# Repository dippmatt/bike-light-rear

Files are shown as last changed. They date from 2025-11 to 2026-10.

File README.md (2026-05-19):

# bike-light-rear

High-visibility rear bicycle light with Bluetooth Low Energy (BLE) control, featuring smart motion detection, ambient light sensing, and efficient single-cell Li-ion power management. Designed for hybrid assembly (pick-and-place for 0402/0603 passives, hand-soldering for connectors and high-value components).

## Hardware architecture

### Compute & wireless
- **BL653 module** (453-00039R) – Nordic nRF52833 SoC with integrated PCB trace antenna, Bluetooth 5.1, and 64 MHz Arm Cortex-M4F
- **Programming** – 2×3 1.27mm SWD header for firmware flashing and debugging
- **System power** – 2.7V from NPM1100 buck regulator optimized for 90-95% battery capacity utilization (3.11V cutoff)

### Sensors (I2C bus @ 2.7V)
- **LIS3DH accelerometer** – 3-axis motion detection (braking / fall detection) for brake/acceleration events, configurable thresholds, interrupt-driven
- **OPT3001 light sensor** – 0.01-83k lux range with human-eye spectral matching for automatic brightness control and day/night mode switching

### High-power LED driver
- **Cree XP-E2** (XPEBRD-L1-0000-00801) – 625nm Red emitter driven at 500mA via PAM2804 step-down constant-current driver
- **Control** – PWM dimming via BL653 GPIO with 100kΩ pull-down for safe default-off state

### Power subsystem
- **Battery** – Single 18350 Li-ion cell (Vapcell 1100mAh, unprotected), 3.11-4.2V operating range
- **Charging** – USB-C PD sink (5.1kΩ CC resistors), NPM1100 linear charger @ 400mA (0Ω ICHG resistor), 4.2V termination
- **Protection** – DW01A IC with dual AO3400A N-channel MOSFETs (drain-to-drain configuration) for over-voltage (4.3V), under-voltage (2.5V), and over-current (>2A) protection
- **Buck regulator** – NPM1100 internal 2.7V @ 150mA output
- **Status monitoring** – CHG and ERR signals routed to BL653 GPIO for firmware-based charge status indication
- **NTC disable** – Thermal monitoring disabled via 10kΩ resistor from NTC pin to AVSS (GND)

### PCB specifications
- **Design tool** – KiCad 9.0 (schema version `20250114`)
- **Test points** – Critical nets labeled for bring-up and debugging (+BATT, +VSYS, +VDD_nRF, GND, I2C_SDA, I2C_SCL)

### Hardware photos

Assembled PCB on the 18350 battery holder (angled view).

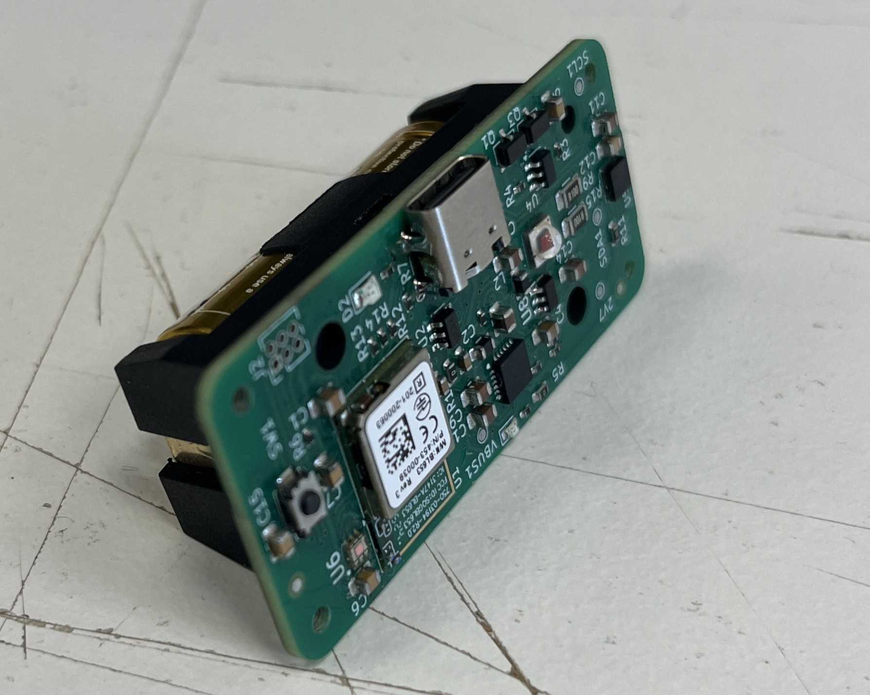
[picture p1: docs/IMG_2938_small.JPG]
Assembled PCB on battery pack


Top of the populated PCB: BL653 (nRF52833), USB-C, tactile switch, RGB status LED, SWD header (J2), and I2C test point pads for the accelerometer and ambient light sensor.

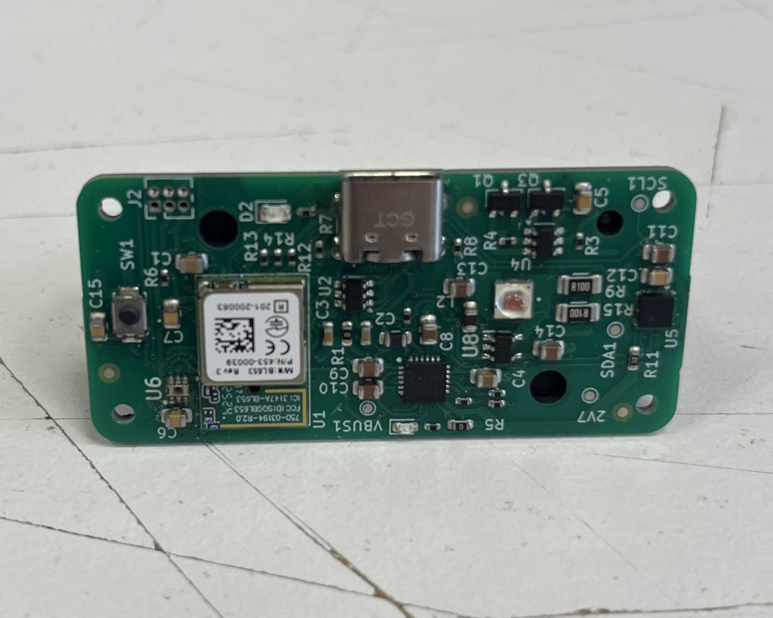
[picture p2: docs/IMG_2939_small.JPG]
PCB top view


Front of the 3D-printed enclosure with the Cree red main LED and status indicator.

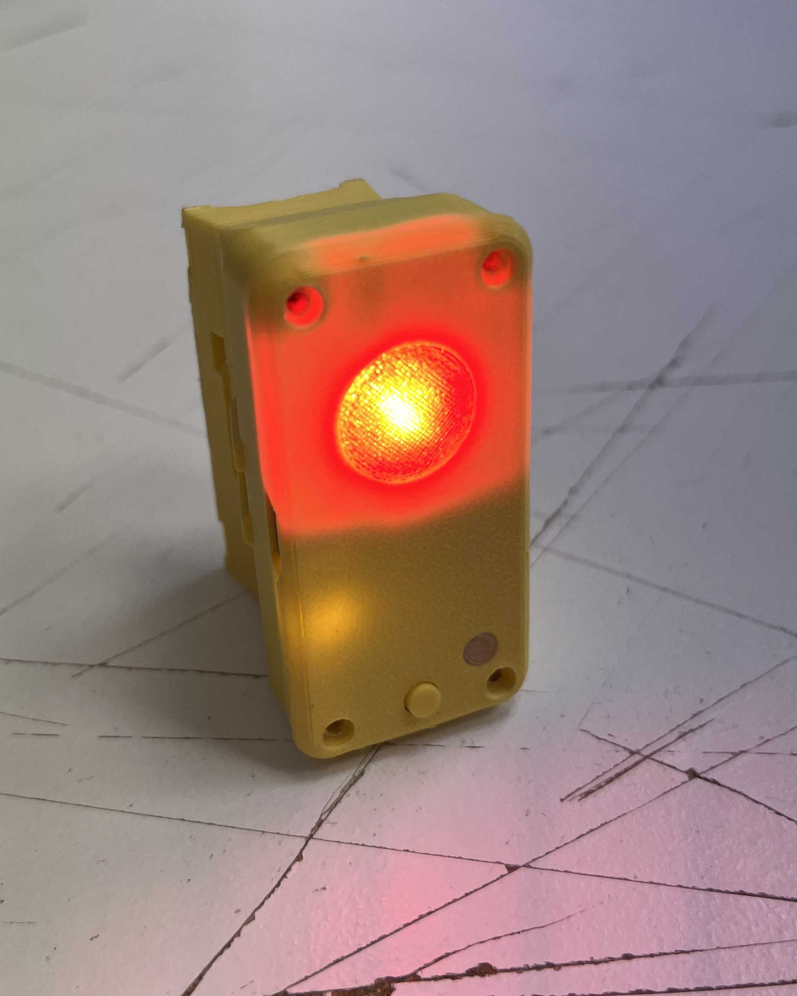
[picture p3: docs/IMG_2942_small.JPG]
Enclosure front, LEDs on


Side of the enclosure showing the USB charge port.

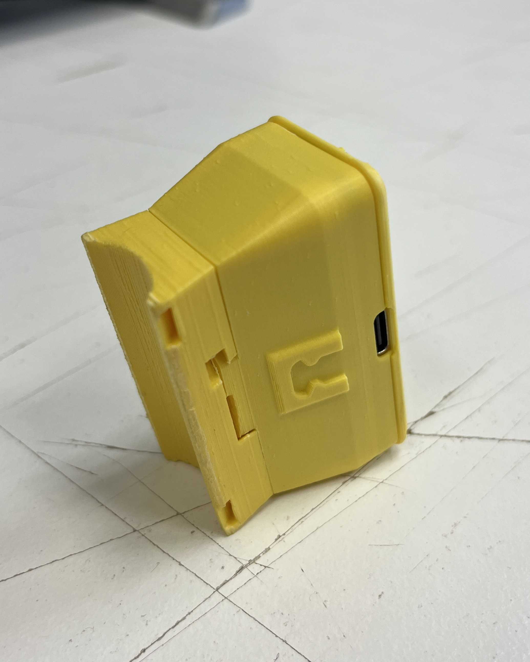
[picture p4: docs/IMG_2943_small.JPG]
Enclosure side, charge port and mount


## Repository layout
- `hardware/` – KiCad project, fabrication-toolkit config, custom libs (`kicad_symbols/`, `kicad_footprints/`, `kicad_3d_models/`), datasheets (markdown format), and generated BOM
- `software/rear_light_peripheral/` – main rear light firmware (Zephyr/nRF Connect SDK), including Smart Mode, BLE peripheral control, charging/idle state, and low-power sleep
- `software/front_light_central/` – proof-of-concept central/front-light firmware (experimental; will evolve later)
- `software/` *(other folders)* – development history and experiments (central/peripheral prototypes, refactors, test projects)
- `docs/` – photos, rendered schematics, mechanical notes, and user-facing manuals
- `LICENSE` – GPLv3 with NonCommercial clause

## Hardware workflow
1. Install KiCad 9.0 or newer.
2. Install the [JLCPCB Fabrication Toolkit](https://github.com/bennymeg/Fabrication-Toolkit) to be able to export the design in the correct format for JLCPCBs [Design For Manufacturing (DFM) Tool](https://jlcdfm.com/).
3. Open `hardware/kicad_project/RearLight.kicad_pro` to access the schematic and PCB.
4. Run ERC/DRC before layout edits; generated artifacts (Gerbers, pick-and-place, STEP export) go to `hardware/kicad_project/production`, which is gitignored and intentionally kept out of releases.
5. Note: Components marked DNP (Do Not Populate) in fabrication files are intended for hand-soldering to minimize assembly costs.

## Firmware

The rear light firmware is built on **Zephyr RTOS** using **nRF Connect SDK toolchain v3.1.1** targeting the **nRF52833 (BL653 module)**. It implements intelligent lighting control with multiple operating modes and supports BLE control via a simple GATT service.

### Features
- **Four Operating Modes**: OFF, 50% continuous, 50/80 flash, and Smart Mode
- **Smart Mode**: Adaptive brightness based on braking detection and ambient light
- **Braking Detection**: Automatic 80% brightness boost during deceleration
- **Ambient Light Sensing**: Adjusts brightness for day/night conditions
- **Auto-Off**: Power-saving mode when stationary for 2.5+ minutes
- **Sensor Buffering**: 3-minute circular buffer for motion and environmental data
- **Power Management**: Low-battery indication and automatic shut-off at low voltage

For complete operating instructions and technical details, see the **[Rear light User Manual](software/rear_light_peripheral/MANUAL.md)**.

### Bluetooth control
The rear light exposes a custom BLE GATT service intended for simple remote control and status reads:

- **Service UUID**: `0xA000`
- **LED status characteristic (read)**: `0xA001` (returns the current state-machine state)
- **Control characteristic (write)**: `0xA002` (write a single byte to request a new state)

Exact UUIDs and behavior live in `software/rear_light_peripheral/inc/ble_service.h` and `software/rear_light_peripheral/src/ble_service.c`. Control writes are rate-limited by a short “state stable” window to avoid fighting local button transitions.

### Firmware environment setup
1. Install the [nRF Command Line Tools](https://www.nordicsemi.com/Products/Development-tools/nrf-command-line-tools) for access to `nrfjprog` and programming utilities.
2. Install [nRF Connect for VS Code](https://www.nordicsemi.com/Products/Development-tools/nrf-connect-for-vs-code) 
3. Within its extension packs, install the **nRF Connect Bare Metal SDK v0.9.0**.
4. Use the nRF Connect for VS Code Toolchain Manager to install the **nRF Connect SDK toolchain v3.1.1** so the project can target the BL653/nRF52833 with the expected compilers and CMake presets.
5. (Optional) Through the nRF Connect tab in VS Code, install the nRF Kconfig and nRF Devicetree extensions.

The main application entry point is `software/rear_light_peripheral/` (see `prj.conf` and `src/main.c`).

Note 1: Device flashing using WSL2  
To connect a J-Link debugger to a WSL instance:
- Open a Windows PowerShell terminal and run:
- `usbipd list`
- `usbipd bind --busid <J-Link BusID>`
- `usbipd attach --wsl --busid <J-Link BusID>`

Note 2: Device does not show up under “Connected Devices” in the nRF Connect VS Code extension
- Install [nRF-Util](https://www.nordicsemi.com/Products/Development-tools/nRF-Util)
- Make nrfutil executable using `chmod +x nrfutil`
- Move the nrfutil executable to a directory in the system $PATH (e.g. /usr/bin)
- Install the _device_ package for nrfutil using `nrfutil install device`
- Restart VSCode. Your device should now show up under _Connected Devices_ in nRF Connect  

## License
This hardware is released under **GPLv3 + NonCommercial**. You may copy, modify, and share for non-commercial use as long as derivatives retain the same license and attribution. See `LICENSE` for full terms.

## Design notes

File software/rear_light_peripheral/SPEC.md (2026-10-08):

# Rear Light Peripheral - Firmware Specification

Behavioural requirements of the rear light firmware. Terms are defined in [CONTEXT.md](./CONTEXT.md). Numeric values are **not** repeated here: the code constant named in `[...]` is the single source of truth. Hard-to-reverse decisions are recorded in [docs/adr](./docs/adr).

Each requirement has an ID so external test lists can reference it.

## 1. System and states

- **SYS-1** The firmware shall have exactly five states: Off, Steady, Flash, Smart and Idle Charging. Their numeric values (0..4 in that order) are part of the BLE contract and shall not change.
- **SYS-2** The Mode Cycle shall be a single configuration point listing the Active Modes in short-press order (currently Smart, Steady, Flash). No other behaviour shall depend on that order or on a specific mode being first or last.
- **SYS-3** All inputs (button, BLE, battery tick, USB edges, sensor detections, flash timer) shall be delivered as events to one queue consumed by a single state machine thread. Only that thread shall change the state or the main LED output. `[APP_EVENT_QUEUE_DEPTH]`
- **SYS-4** If the event queue is full, the new event shall be dropped and a message logged. No retry is made.
- **SYS-5** If initialization of the main LED, the status LED or the button fails, the firmware shall perform a software reset instead of returning from `main()`. Failure of the battery ADC, the sensors or BLE initialization shall not stop startup. See ADR-0003.
- **SYS-6** The firmware shall not use a watchdog. A hang is not recovered. (Possible future feature.)

## 2. Boot

- **BOOT-1** At boot the firmware shall enter Idle Charging if the reset cause is a power-on reset and USB power is present.
- **BOOT-2** For every other reset cause (button wake from Deep Sleep, power-on reset without USB power, brownout, watchdog, software or pin reset, or a non-power-on reset with USB power) the firmware shall enter the first Active Mode of the Mode Cycle.
- **BOOT-3** Plugging in USB power while in Deep Sleep resets the MCU in hardware, so by BOOT-1 the light shall come up in Idle Charging.
- **BOOT-4** The press that wakes the light from Deep Sleep shall only wake it. It shall produce no short or long press event. A button still held after boot produces no event, and the next press edge counts as a new press.

## 3. Button

- **BTN-1** A press released before 1 s shall be a short press. It acts on release. `[LONG_PRESS_SAMPLES, SAMPLE_INTERVAL_MS]`
- **BTN-2** A press held for 1 s or longer shall be a long press. It acts at the 1 s mark without waiting for release.
- **BTN-3** Press edges closer together than the debounce time shall be ignored. `[DEBOUNCE_MS]`
- **BTN-4** A short press shall act as follows:
  - Off: enter the first Active Mode.
  - Idle Charging: enter the first Active Mode.
  - An Active Mode that is not the last in the Mode Cycle, inside the Selection Window (BTN-8): enter the next Active Mode.
  - The last Active Mode, or any Active Mode after the Selection Window has closed: enter Idle Charging if USB power is present, otherwise enter Deep Sleep.
- **BTN-5** A long press in any state shall enter Deep Sleep, whether or not USB power is present.
- **BTN-6** Before entering Deep Sleep the firmware shall wait for the button to be released, up to a limit, so that a still-held button does not wake the device immediately. If the limit is exceeded it proceeds anyway. `[POWEROFF_RELEASE_WAIT_MS, POWEROFF_RELEASE_POLL_MS]`
- **BTN-7** If the Deep Sleep wake configuration fails, the firmware shall stay awake in Off with the button working instead of sleeping.
- **BTN-8** Every transition from an inactive state (Deep Sleep, Off, Idle Charging) to an Active Mode shall open the Selection Window, whether caused by the button, a boot or reset, or a BLE request. Changes between Active Modes, by button or by BLE, shall neither open nor restart it. The window shall be counted in battery ticks (no dedicated timer), so its length is between (N-1) and N tick periods, about 15 to 20 s. `[MODE_SELECT_WINDOW_BATTERY_TICKS, BATTERY_SAMPLE_INTERVAL_MS]`
- **BTN-9** Closing the Selection Window shall have no visible effect. Only the effect of the next short press changes (BTN-4). USB power is evaluated at the time of that press. A long press is unaffected.
## 4. Power states

- **PWR-1** In Deep Sleep the main LED and the status LED shall be off, and BLE shall be unreachable. Only the button (or USB power appearing, see BOOT-3) wakes the device.
- **PWR-2** Off shall be entered only by a BLE request (BLE-3). It shall have no timeout and shall not enter Deep Sleep on its own.
- **PWR-3** In Off and Idle Charging the main LED shall be off.
- **PWR-4** Every automatic power-off (Smart stationary auto-off, critical battery, USB removal in Idle Charging) and the long press shall enter Deep Sleep. Only the short-press cycle (BTN-4) has a USB-dependent end.

## 5. Light output

- **LED-1** Steady shall show Base continuously. `[LIGHT_PULSE_BASE]`
- **LED-2** Flash shall show Base, with a double flash to Peak every cycle: Peak for one step, Base for one step, Peak for one step, Base for the rest of the cycle. The first double flash occurs one cycle after entering Flash. `[FLASH_CYCLE_MS, FLASH_STEP_MS, FLASH_REST_MS, LIGHT_PULSE_PEAK]`
- **LED-3** The PWM period shall be fixed. `[LIGHT_PWM_PERIOD_USEC]`
- **LED-4** Leaving Flash shall stop the flash timer. A flash step event arriving in any other state shall be ignored.

## 6. Smart

- **SMART-1** On entering Smart the main LED shall be off, and the braking and dark flags shall be cleared. Sensor sampling shall start. Sampling shall stop when Smart is left. The accelerometer and the light sensor shall be sampled on independent schedules. `[ACCEL_SAMPLING_INTERVAL_MS, LIGHT_SAMPLING_INTERVAL_MS, SENSOR_TICK_MS]`
- **SMART-2** Brightness in Smart shall be chosen by priority: braking gives Peak, otherwise dark gives Base, otherwise off.
- **SMART-3** Braking is judged on the filtered Z acceleration (SMART-8, SMART-9). The sensor is mounted with Z along the direction of travel and positive Z means decelerating and negative Z means accelerating. Braking shall start when the filtered value stays above the threshold for the start confirm time, and end when it stays at or below the same threshold for the stop confirm time plus the hold time, so the light keeps shining for the hold time after the braking phase has ended. Braking again within that time keeps the light on without a gap. The threshold is +5.0 m/s^2 (not g). `[BRAKING_ACCEL_THRESHOLD_MILLI, BRAKING_START_CONFIRM_MS, BRAKING_STOP_CONFIRM_MS, BRAKING_HOLD_MS]`
- **SMART-4** Darkness starts after consecutive samples below the dark threshold and ends after consecutive samples at or above the bright threshold. The two thresholds differ (hysteresis). `[AMBIENT_DARK_THRESHOLD_MILLILUX, AMBIENT_BRIGHT_THRESHOLD_MILLILUX, AMBIENT_SAMPLES_REQUIRED]`
- **SMART-5** After the stationary timeout of uninterrupted samples with acceleration magnitude within the tolerance band around 1g, the firmware shall enter Deep Sleep (auto-off). Any sample outside the band resets the count. A failed accelerometer read neither counts nor resets. See ADR-0002. `[STATIONARY_TIMEOUT_MS, STATIONARY_MIN_MAGNITUDE_SQ, STATIONARY_MAX_MAGNITUDE_SQ]`
- **SMART-6** Braking, darkness and auto-off events arriving in any state other than Smart shall be ignored.
- **SMART-7** If a sensor failed initialization, Smart shall continue with the remaining one. No light sensor means the LED stays off. No accelerometer means no braking and no auto-off.
- **SMART-8** The filtered Z acceleration shall be the raw Z acceleration minus a slow baseline (removes the gravity component from mounting tilt and slope). The baseline shall be seeded from the first accelerometer sample after entering Smart, follow Z with a first-order low-pass, and be frozen while braking is active or a braking start is being confirmed. `[BRAKING_BASELINE_TAU_MS]`
- **SMART-9** The baseline-corrected Z acceleration shall be averaged over a short window before it is compared to the threshold. A window of one sample disables the smoothing. `[BRAKING_SMOOTHING_MS]`
- **SMART-10** The accelerometer output data rate shall be set explicitly at start-up (not left at the driver default) and shall not be lower than the polling rate. If setting it fails, a message is logged and the driver default is used. `[ACCEL_ODR_HZ]`
- **SMART-11** Detection times (braking confirm, smoothing, baseline, stationary timeout) shall be defined in milliseconds, and the sample counts derived from them rounded up, so changing a sampling interval does not change a detection time. Ambient light detection is defined in light sensor samples. `[MS_TO_SAMPLES]`

## 7. USB power and charging

- **USB-1** USB power presence shall be polled, and an event posted only on a change. A newly plugged or unplugged cable may therefore be noticed up to one poll interval late. `[USB_POLL_INTERVAL_MS]`
- **USB-2** Plugging in USB power shall never change the state. Only the status LED changes.
- **USB-3** Removing USB power while in Idle Charging shall enter Deep Sleep. In any other state it shall only change the status LED.
- **USB-4** The firmware shall treat USB power present as Charging in every awake state. It has no knowledge of charge completion, and charging itself is done by autonomous hardware.

## 8. Battery

- **BAT-1** In every awake state the battery voltage shall be sampled periodically. `[BATTERY_SAMPLE_INTERVAL_MS]`
- **BAT-2** A failed reading shall count as 0 mV, so a battery that cannot be measured is treated as empty.
- **BAT-3** After consecutive samples below the critical voltage the firmware shall enter Deep Sleep, in every state. `[BATTERY_CRITICAL_MV, BATTERY_CONSECUTIVE]`
- **BAT-4** After consecutive samples below the low voltage the battery shall be Low. After consecutive samples at or above it, the battery shall be OK again. Entering and leaving Low use the same voltage. `[BATTERY_LOW_MV, BATTERY_CONSECUTIVE]`
- **BAT-5** Low battery shall not change the main LED. Only the status LED and the critical cut-off (BAT-3) react.
- **BAT-6** Battery readings while USB power is present are not trustworthy and no special handling exists.
- **BAT-7** Waking from Deep Sleep with a critical battery shall turn the light on until the critical cut-off triggers again, as for any other wake.

## 9. Status LED

- **STAT-1** The status LED shall show, in priority order:
  1. Low battery: slow blink. `[BLINK_INTERVAL_LOW_BATTERY_MS]`
  2. Charging: fast blink. `[BLINK_INTERVAL_CHARGING_MS]`
  3. Any Active Mode: solid on.
  4. Otherwise: off.
- **STAT-2** The status LED is visible to the rider. This is the only low-battery warning, and the main LED is unaffected until the critical cut-off.

## 10. BLE

- **BLE-1** Whenever the device is awake it shall advertise as connectable with service UUID `[BLE_SERVICE_UUID]`, restart advertising after a disconnect, and retry a failed start. Only one connection at a time is supported. A connection shall never keep the device awake. Only Off does.
- **BLE-2** Reading characteristic `[BLE_LED_STATUS_UUID]` shall return the current state as one byte (SYS-1 values).
- **BLE-3** Writing characteristic `[BLE_CONTROL_UUID]` with one byte at offset 0 shall request a state. Valid requests are Off, Steady, Flash and Smart. Idle Charging cannot be requested because only USB power sets it.
- **BLE-4** A write with a length other than one byte or a non-zero offset shall fail with an ATT error. Any other write shall return success, even if the request is ignored.
- **BLE-5** A request shall be ignored if it is not a valid request (BLE-3), equals the current state, or arrives within the stable window after the last state change (including boot). `[BLE_STABLE_WINDOW_MS]`
- **BLE-6** A request for Steady, Flash or Smart shall be applied in Idle Charging.
- **BLE-7** A request for Off shall keep the device awake and connectable.
- **BLE-8** The client reads the result back from the status characteristic. Writes are not authenticated. See ADR-0001.

## 11. Hardware assumptions

- **HW-1** The charger is autonomous hardware that charges in Deep Sleep and with a flat battery.
- **HW-2** Appearing USB power resets the MCU in hardware while in Deep Sleep.
- **HW-3** The accelerometer is mounted with Z along the direction of travel, with +Z pointing backward (against the direction of travel), so braking reads positive and accelerating reads negative.
- **HW-4** The status LED is visible to the rider.

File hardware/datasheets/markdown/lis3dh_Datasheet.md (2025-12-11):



# MEMS digital output motion sensor: ultra-low-power high-performance 3-axis "nano" accelerometer

Datasheet - production data



#### **Features**

- Wide supply voltage, 1.71 V to 3.6 V
- Independent IO supply (1.8 V) and supply voltage compatible
- Ultra-low-power mode consumption down to 2 µA
- ±2g/±4g/±8g/±16g dynamically selectable full scale
- I<sup>2</sup>C/SPI digital output interface
- 16-bit data output
- 2 independent programmable interrupt generators for free-fall and motion detection
- 6D/4D orientation detection
- Free-fall detection
- Motion detection
- Embedded temperature sensor
- · Embedded self-test
- Embedded 32 levels of 16-bit data output FIFO
- 10000 g high shock survivability
- ECOPACK®, RoHS and "Green" compliant

### **Applications**

- Motion activated functions
- Free-fall detection
- Click/double-click recognition
- Intelligent power saving for handheld devices
- Pedometers

- · Display orientation
- · Gaming and virtual reality input devices
- Impact recognition and logging
- Vibration monitoring and compensation

#### Description

The LIS3DH is an ultra-low-power highperformance three-axis linear accelerometer belonging to the "nano" family, with digital I<sup>2</sup>C/SPI serial interface standard output. The device features ultra-low-power operational modes that allow advanced power saving and smart embedded functions.

The LIS3DH has dynamically user-selectable full scales of  $\pm 2g/\pm 4g/\pm 8g/\pm 16g$  and is capable of measuring accelerations with output data rates from 1 Hz to 5.3 kHz. The self-test capability allows the user to check the functioning of the sensor in the final application. The device may be configured to generate interrupt signals using two independent inertial wake-up/free-fall events as well as by the position of the device itself. Thresholds and timing of interrupt generators are programmable by the end user on the fly. The LIS3DH has an integrated 32-level first-in, firstout (FIFO) buffer allowing the user to store data in order to limit intervention by the host processor. The LIS3DH is available in small thin plastic land grid array package (LGA) and is guaranteed to operate over an extended temperature range from -40 °C to +85 °C.

Table 1. Device summary

| Order codes | Temp.<br>range [°C] | Package | Packaging |
|---|---|---|---|
| LIS3DHTR | -40 to +85 | LGA-16  | Tape and reel |

Contents LIS3DH

## **Contents**

| Section | Number | Title | Page |
|---|---|---|---|
| 1 | | Block diagram and pin description | 8 |
| | 1.1 | Block diagram | 8 |
| | 1.2 | Pin description | 8 |
| 2 | | Mechanical and electrical specifications | 10 |
| | 2.1 | Mechanical characteristics | 10 |
| | 2.2 | Temperature sensor characteristics | 12 |
| | 2.3 | Electrical characteristics | 13 |
| | 2.4 | Communication interface characteristics | 13 |
| | | 2.4.1 SPI - serial peripheral interface | 13 |
| | | 2.4.2 I2C - Inter IC control interface | 14 |
| | 2.5 | Absolute maximum ratings | 15 |
| 3 | | Terminology and functionality | 16 |
| | 3.1 | Terminology | 16 |
| | | 3.1.1 Sensitivity | 16 |
| | | 3.1.2 Zero-g level | 16 |
| | 3.2 | Functionality | 16 |
| | | 3.2.1 High-resolution, normal mode, low-power mode | 16 |
| | | 3.2.2 Self-test | 17 |
| | | 3.2.3 6D / 4D orientation detection | 18 |
| | | 3.2.4 "Sleep-to-wake" and "Return-to-sleep" | 18 |
| | 3.3 | Sensing element | 18 |
| | 3.4 | IC interface | 18 |
| | 3.5 | Factory calibration | 19 |
| | 3.6 | FIFO | 19 |
| | 3.7 | Auxiliary ADC and temperature sensor | 19 |
| 4 | | Application hints | 20 |
| | 4.1 | Soldering information | 20 |
| 5 | | Digital main blocks | 22 |
| | 5.1 | FIFO | 22 |
| Section | Title | Page | |
| 5.1.1 | Bypass mode | 22 | |
| 5.1.2 | FIFO mode | 22 | |
| 5.1.3 | Stream mode | 23 | |
| 5.1.4 | Stream-to-FIFO mode | 23 | |
| 5.1.5 | Retrieving data from FIFO | 23 | |
| 6 | Digital interfaces | 24 | |
| 6.1 | I2C serial interface | 24 | |
| 6.1.1 | I2C operation | 25 | |
| 6.2 | SPI bus interface | 27 | |
| 6.2.1 | SPI read | 28 | |
| 6.2.2 | SPI write | 29 | |
| 6.2.3 | SPI read in 3-wire mode | 30 | |
| 7 | Register mapping | 31 | |
| 8 | Registers description | 33 | |
| 8.1 | STATUS_REG_AUX (07h) | 33 | |
| 8.2 | OUT_ADC1_L (08h), OUT_ADC1_H (09h) | 33 | |
| 8.3 | OUT_ADC2_L (0Ah), OUT_ADC2_H (0Bh) | 33 | |
| 8.4 | OUT_ADC3_L (0Ch), OUT_ADC3_H (0Dh) | 33 | |
| 8.5 | WHO_AM_I (0Fh) | 34 | |
| 8.6 | CTRL_REG0 (1Eh) | 34 | |
| 8.7 | TEMP_CFG_REG (1Fh) | 34 | |
| 8.8 | CTRL_REG1 (20h) | 35 | |
| 8.9 | CTRL_REG2 (21h) | 36 | |
| 8.10 | CTRL_REG3 (22h) | 36 | |
| 8.11 | CTRL_REG4 (23h) | 37 | |
| 8.12 | CTRL_REG5 (24h) | 38 | |
| 8.13 | CTRL_REG6 (25h) | 38 | |
| 8.14 | REFERENCE (26h) | 39 | |
| 8.15 | STATUS_REG (27h) | 39 | |
| 8.16 | OUT_X_L (28h), OUT_X_H (29h) | 40 | |
| 8.17 | OUT_Y_L (2Ah), OUT_Y_H (2Bh) | 40 | |
| 8.18 | OUT_Z_L (2Ch), OUT_Z_H (2Dh) | 40 | |



LIS3DH Contents

| Section | Title |
|---|---|
| 8.19 | FIFO_CTRL_REG (2Eh) |
| 8.20 | FIFO_SRC_REG (2Fh) |
| 8.21 | INT1_CFG (30h) |
| 8.22 | INT1_SRC (31h) |
| 8.23 | INT1_THS (32h) |
| 8.24 | INT1_DURATION (33h) |
| 8.25 | INT2_CFG (34h) |
| 8.26 | INT2_SRC (35h) |
| 8.27 | INT2_THS (36h) |
| 8.28 | INT2_DURATION (37h) |
| 8.29 | CLICK_CFG (38h) |
| 8.30 | CLICK_SRC (39h) |
| 8.31 | CLICK_THS (3Ah) |
| 8.32 | TIME_LIMIT (3Bh) |
| 8.33 | TIME_LATENCY (3Ch) |
| 8.34 | TIME WINDOW (3Dh) |
| 8.35 | ACT_THS (3Eh) |
| 8.36 | ACT_DUR (3Fh) |
| 9 | Package information |
| 9.1 | LGA-16 package information |
| 9.2 | LGA-16 packing information |
| 10 | Revision history |

LIS3DH List of tables

## List of tables

| Table 1.  | Device summary | 1 |
|---|---|---|
| Table 2.  | Pin description | 9 |
| Table 3.  | Internal pull-up values (typ.) for SDO/SA0 pin | 9 |
| Table 4.  | Mechanical characteristics | 10 |
| Table 5.  | Temperature sensor characteristics | 12 |
| Table 6.  | Electrical characteristics | 12 |
| Table 7.  | SPI slave timing values | 13 |
| Table 8.  | I <sup>2</sup> C slave timing values | 14 |
| Table 9.  | Absolute maximum ratings | 15 |
| Table 10. | Operating mode selection | 16 |
| Table 11. | Turn-on time for operating mode transition | 17 |
| Table 12. | Current consumption of operating modes | 17 |
| Table 13. | Internal pin status | 21 |
| Table 14. | Serial interface pin description | 24 |
| Table 15. | I <sup>2</sup> C terminology | 24 |
| Table 16. | SAD+Read/Write patterns | 25 |
| Table 17. | Transfer when master is writing one byte to slave | 25 |
| Table 18. | Transfer when master is writing multiple bytes to slave | |
| Table 19. | Transfer when master is receiving (reading) one byte of data from slave | |
| Table 20. | Transfer when master is receiving (reading) multiple bytes of data from slave | 26 |
| Table 21. | Register address map | 31 |
| Table 22. | STATUS_REG_AUX register | 33 |
| Table 23. | STATUS_REG_AUX description | |
| Table 24. | WHO_AM_I register | |
| Table 25. | CTRL_REG0 register | |
| Table 26. | CTRL_REG0 description | |
| Table 27. | TEMP_CFG_REG register | |
| Table 28. | TEMP_CFG_REG description | |
| Table 29. | CTRL_REG1 register | |
| Table 30. | CTRL_REG1 description | |
| Table 31. | Data rate configuration | |
| Table 32. | CTRL_REG2 register | |
| Table 33. | CTRL_REG2 description | |
| Table 34. | High-pass filter mode configuration | |
| Table 35. | CTRL_REG3 register | |
| Table 36. | CTRL_REG3 description | |
| Table 37. | CTRL_REG4 register | |
| Table 38. | CTRL_REG4 description | |
| Table 39. | Self-test mode configuration | |
| Table 40. | CTRL_REG5 register | |
| Table 41. | CTRL_REG5 description | |
| Table 42. | CTRL_REG6 register | |
| Table 43. | CTRL_REG6 description | |
| Table 44. | REFERENCE register | |
| Table 45. | REFERENCE register description | |
| Table 46. | STATUS register | 39 |
| Table 47. | STATUS register description | |
| Table 48. | REFERENCE register | 40 |
| Table | Description | Page |
| Table 49. | REFERENCE register description | 40 |
| Table 50. | FIFO mode configuration | 40 |
| Table 51. | FIFO_SRC_REG register | 41 |
| Table 52. | FIFO_SRC_REG description | 41 |
| Table 53. | INT1_CFG register | 41 |
| Table 54. | INT1_CFG description | 41 |
| Table 55. | Interrupt mode | 42 |
| Table 56. | INT1_SRC register | 42 |
| Table 57. | INT1_SRC description | 42 |
| Table 58. | INT1_THS register | 43 |
| Table 59. | INT1_THS description | 43 |
| Table 60. | INT1_DURATION register | 43 |
| Table 61. | INT1_DURATION description | 43 |
| Table 62. | INT2_CFG register | 44 |
| Table 63. | INT2_CFG description | 44 |
| Table 64. | Interrupt mode | 44 |
| Table 65. | INT2_SRC register | 45 |
| Table 66. | INT2_SRC description | 45 |
| Table 67. | INT2_THS register | 45 |
| Table 68. | INT2_THS description | 45 |
| Table 69. | INT2_DURATION register | 46 |
| Table 70. | INT2_DURATION description | 46 |
| Table 71. | CLICK_CFG register | 46 |
| Table 72. | CLICK_CFG description | 46 |
| Table 73. | CLICK_SRC register | 47 |
| Table 74. | CLICK_SRC description | 47 |
| Table 75. | CLICK_THS register | 47 |
| Table 76. | CLICK_THS description | 47 |
| Table 77. | TIME_LIMIT register | 47 |
| Table 78. | TIME_LIMIT description | 47 |
| Table 79. | TIME_LATENCY register | 48 |
| Table 80. | TIME_LATENCY description | 48 |
| Table 81. | TIME_WINDOW register | 48 |
| Table 82. | TIME_WINDOW description | 48 |
| Table 83. | ACT_THS register | 48 |
| Table 84. | ACT_THS description | 48 |
| Table 85. | ACT_DUR register | 48 |
| Table 86. | ACT_DUR description | 48 |
| Table 87. | Reel dimensions for carrier tape of LGA-16 package | 52 |
| Table 88. | Document revision history | 53 |



LIS3DH List of figures

## **List of figures**

| Figure | Title | Page |
|---|---|---|
| Figure 1.  | Block diagram | 1 |
| Figure 2.  | Pin connections | 1 |
| Figure 3.  | SPI slave timing diagram | 1 |
| Figure 4.  | I2C slave timing diagram | 1 |
| Figure 5.  | LIS3DH electrical connections | 2 |
| Figure 6.  | Read and write protocol | 2 |
| Figure 7.  | SPI read protocol | 2 |
| Figure 8.  | Multiple byte SPI read protocol (2-byte example) | 2 |
| Figure 9.  | SPI write protocol | 2 |
| Figure 10. | Multiple byte SPI write protocol (2-byte example) | 2 |
| Figure 11. | SPI read protocol in 3-wire mode | 3 |
| Figure 12. | LGA-16 package outline and mechanical dimensions | 5 |
| Figure 13. | Carrier tape information for LGA-16 package | 5 |
| Figure 14. | LGA-16 package orientation in carrier tape | 5 |
| Figure 15. | Reel information for carrier tape of LGA-16 package | 5 |



## 1 Block diagram and pin description

### 1.1 Block diagram

Figure 1. Block diagram



### 1.2 Pin description

Figure 2. Pin connections



Table 2. Pin description

| Pin# | Name | Function |
|---|---|---|
| 1 | Vdd_IO | Power supply for I/O pins |
| 2 | NC | Not connected |
| 3 | NC | Not connected |
| 4 | SCL<br>SPC | I2C serial clock (SCL)<br>SPI serial port clock (SPC) |
| 5 | GND | 0 V supply |
| 6 | SDA<br>SDI<br>SDO | I2C serial data (SDA)<br>SPI serial data input (SDI)<br>3-wire interface serial data output (SDO) |
| 7(1) | SDO<br>SA0 | SPI serial data output (SDO)<br>I2C less significant bit of the device address (SA0) |
| 8 | CS | SPI enable<br>I2C/SPI mode selection:<br>1: SPI idle mode / I2C communication enabled<br>0: SPI communication mode / I2C disabled |
| 9 | INT2 | Inertial interrupt 2 |
| 10 | RES | Connect to GND |
| 11 | INT1 | Inertial interrupt 1 |
| 12 | GND | 0 V supply |
| 13 | ADC3 | Analog-to-digital converter input 3 |
| 14 | Vdd | Power supply |
| 15 | ADC2 | Analog-to-digital converter input 2 |
| 16 | ADC1 | Analog-to-digital converter input 1 |

<sup>1.</sup> SDO/SA0 pin is internally pulled up. Refer to *Table 3* for the internal pull-up values (typ.).

Table 3. Internal pull-up values (typ.) for SDO/SA0 pin

| | Resistor value for SDO/SA0 pin |
|---|---|
| Vdd_IO | Typ. (kΩ) |
| 1.7 V  | 54.4 |
| 1.8 V  | 49.2 |
| 2.5 V  | 30.4 |
| 3.6 V  | 20.4 |



10/54

## 2 Mechanical and electrical specifications

### 2.1 Mechanical characteristics

Vdd = 2.5 V, T = 25 °C unless otherwise noted (a)

**Table 4. Mechanical characteristics** 

| Symbol | Parameter | Test conditions | Min. | Typ.(1) | Max. | Unit |
|---|---|---|---|---|---|---|
| FS | Measurement range(2) | FS bit set to 00 | | ±2.0 | | |
| | | FS bit set to 01 | | ±4.0 | | |
| | | FS bit set to 10 | | ±8.0 | | |
| | | FS bit set to 11 | | ±16.0 | | g |
| So | Sensitivity | FS bit set to 00;<br>High-resolution mode | | 1 | | m <i>g</i> /digit |
| | | FS bit set to 00;<br>Normal mode | | 4 | | m <i>g</i> /digit |
| | | FS bit set to 00;<br>Low-power mode | | 16 | | m <i>g</i> /digit |
| | | FS bit set to 01;<br>High-resolution mode | | 2 | | m <i>g</i> /digit |
| | | FS bit set to 01;<br>Normal mode | | 8 | | m <i>g</i> /digit |
| | | FS bit set to 01;<br>Low-power mode | | 32 | | m <i>g</i> /digit |
| | | FS bit set to 10;<br>High-resolution mode | | 4 | | m <i>g</i> /digit |
| | | FS bit set to 10;<br>Normal mode | | 16 | | m <i>g</i> /digit |
| | | FS bit set to 10;<br>Low-power mode | | 64 | | m <i>g</i> /digit |
| | | FS bit set to 11;<br>High-resolution mode | | 12 | | m <i>g</i> /digit |
| | | FS bit set to 11;<br>Normal mode | | 48 | | m <i>g</i> /digit |
| | | FS bit set to 11;<br>Low-power mode | | 192 | | m <i>g</i> /digit |
| TCSo | Sensitivity change vs temperature | FS bit set to 00 | | 0.01 | | %/°C |
| TyOff  | Typical zero- <i>g</i> level offset accuracy(3),(4) | FS bit set to 00 | | ±40 | | m <i>g</i> |

a. The product is factory calibrated at 2.5 V. The operational power supply range is from 1.71 V to 3.6 V.

DocID17530 Rev 2

| Table | 4 11/4  | ahani | ام امم | h - =  | taristics |
|---|---|---|---|---|---|
| Iania | 4 IVI A | cnanı | cai ci | naracı | IDIICE |

| Symbol | Parameter | Test conditions | Min. | Typ.(1) | Max. | Unit |
|---|---|---|---|---|---|---|
| TCOff  | Zero- <i>g</i> level change vs temperature | Max delta from 25 °C | | ±0.5 | | m <i>g</i> /°C  |
| An | Acceleration noise density | FS bit set to 00, High-Resolution mode ( <i>Table 10</i> ), ODR > 1300 Hz | | 220 | | μ <i>g</i> /√Hz |
| Vst | Self-test<br>output change(5)(6)(7) | FS bit set to 00<br>X-axis; Normal mode | 17 | | 360  | LSb |
| | | FS bit set to 00<br>Y-axis; Normal mode | 17 | | 360  | LSb |
| | | FS bit set to 00<br>Z-axis; Normal mode | 17 | | 360  | LSb |
| Top | Operating temperature range | | -40  | | +85  | °C |

- 1. Typical specifications are not guaranteed.
- 2. Verified by wafer level test and measurement of initial offset and sensitivity.
- 3. Typical zero-g level offset value after MSL3 preconditioning.
- 4. Offset can be eliminated by enabling the built-in high-pass filter.
- 5. The sign of "Self-test output change" is defined by the ST bits in CTRL\_REG4 (23h), for all axes.
- 6. "Self-test output change" is defined as the absolute value of:

  OUTPUT[LSb]<sub>(Self test enabled)</sub> OUTPUT[LSb]<sub>(Self test disabled)</sub>. 1LSb = 4 mg at 10-bit representation, ±2 g full scale.
- 7. After enabling the self-test, correct data is obtained after two samples (low-power mode / normal mode) or after eight samples (high-resolution mode).



### 2.2 Temperature sensor characteristics

Vdd = 2.5 V, T = 25 °C unless otherwise noted (b)

Table 5. Temperature sensor characteristics

| Symbol | Parameter | Test condition | Min. | Typ.(1) | Max. | Unit |
|---|---|---|---|---|---|---|
| TSDr | Temperature sensor output change vs temperature | | | 1 | | digit/°C(2) |
| TODR | Temperature refresh rate | | | ODR | | Hz |
| Top | Operating temperature range | | -40  | | +85  | °C |

<sup>1.</sup> Typical specifications are not guaranteed.

#### 2.3 Electrical characteristics

Vdd = 2.5 V, T = 25 °C unless otherwise noted (c)

**Table 6. Electrical characteristics** 

| Symbol | Parameter | Test conditions | Min. | Typ.(1) | Max. | Unit |
|---|---|---|---|---|---|---|
| Vdd | Supply voltage | | 1.71 | 2.5 | 3.6 | V |
| Vdd_IO | I/O pins supply voltage(2) | | 1.71 | | Vdd+0.1 | V |
| Idd | Current consumption in normal mode | 50 Hz ODR | | 11 | | μA |
| Idd | Current consumption in normal mode | 1 Hz ODR | | 2 | | μA |
| IddLP  | Current consumption in low-power mode  | 50 Hz ODR | | 6 | | μA |
| IddPdn | Current consumption in power-down mode | | | 0.5 | | μA |
| VIH | Digital high-level input voltage | | 0.8*Vdd_IO | | | V |
| VIL | Digital low-level input voltage | | | | 0.2*Vdd_IO | V |
| VOH | High-level output voltage | | 0.9*Vdd_IO | | | V |
| VOL | Low-level output voltage | | | | 0.1*Vdd_IO | V |
| BW | System bandwidth(3) | | | ODR/2 | | Hz |
| Top | Operating temperature range | | -40 | | +85 | °C |

<sup>1.</sup> Typical specification are not guaranteed.

577

<sup>2. 8-</sup>bit resolution.

<sup>2.</sup> It is possible to remove Vdd maintaining Vdd\_IO without blocking the communication busses, in this condition the measurement chain is powered off.

<sup>3.</sup> Refer to Table 25 for the ODR value and configuration.

b. The product is factory calibrated at 2.5 V. Temperature sensor operation is guaranteed in the range 2 V - 3.6 V.

c. The product is factory calibrated at 2.5 V. The operational power supply range is from 1.71 V to 3.6 V.

#### 2.4 **Communication interface characteristics**

#### 2.4.1 SPI - serial peripheral interface

Subject to general operating conditions for Vdd and Top.

Table 7. SPI slave timing values

| Symbol | Parameter | Value (1) | | Unit |
|---|---|---|-----|---|
| | | Min | Max | |
| tc(SPC)  | SPI clock cycle | 100 | | ns |
| fc(SPC)  | SPI clock frequency | | 10  | MHz  |
| tsu(CS)  | CS setup time | 5 | | ns |
| th(CS) | CS hold time | 20 | | ns |
| tsu(SI)  | SDI input setup time | 5 | | ns |
| th(SI) | SDI input hold time | 15 | | ns |
| tv(SO) | SDO valid output time | | 50  | ns |
| th(SO) | SDO output hold time | 5 | | ns |
| tdis(SO) | SDO output disable time | | 50  | ns |

Values are guaranteed at 10 MHz clock frequency for SPI with both 4 and 3 wires, based on characterization results, not tested in production.

CS (1) (1) SPC (1) (1)  $t_{\text{su}(\text{SI})}$  $t_{\text{h}(\text{SI})}$ SDI LSBIN (1) MSB IN (1) t<sub>dis(SO)</sub> SDO - (1) MSB OUT LSBOUT

Figure 3. SPI slave timing diagram

1. When no communication is ongoing, data on SDO is driven by internal pull-up resistors.

Measurement points are done at 0.2·Vdd\_IO and 0.8·Vdd\_IO, for both input and output Note: ports.

#### I<sup>2</sup>C - Inter IC control interface 2.4.2

Subject to general operating conditions for Vdd and top.

Table 8. I<sup>2</sup>C slave timing values

| Symbol | Parameter | $I2C$ standard | | $I2C$ fast mode (1) | | Unit |
|---|---|---|---|---|-----|---|
| | | Min | Max  | Min | Max | |
| $f(SCL)$ | SCL clock frequency | 0 | 100  | 0 | 400 | kHz  |
| $tw(SCLL)$  | SCL clock low time | 4.7 | | 1.3 | | μs |
| $tw(SCLH)$  | SCL clock high time | 4.0 | | 0.6 | | μs |
| $tsu(SDA)$  | SDA setup time | 250 | | 100 | | ns |
| $th(SDA)$ | SDA data hold time | 0 | 3.45 | 0 | 0.9 | μs |
| $th(ST)$ | START condition hold time | 4 | | 0.6 | | μs |
| $tsu(SR)$ | Repeated START condition setup time | 4.7 | | 0.6 | | μs |
| $tsu(SP)$ | STOP condition setup time | 4 | | 0.6 | | μs |
| $tw(SP:SR)$ | Bus free time between STOP and START condition | 4.7 | | 1.3 | | μs |

<sup>1.</sup> Data based on standard I<sup>2</sup>C protocol requirement, not tested in production.

Figure 4. I<sup>2</sup>C slave timing diagram REPEATED START START SDA SCL

Note: Measurement points are done at 0.2·Vdd\_IO and 0.8·Vdd\_IO, for both ports.

# ST

ST

#### **Absolute maximum ratings** 2.5

Stresses above those listed as "absolute maximum ratings" may cause permanent damage to the device. This is a stress rating only and functional operation of the device under these conditions is not implied. Exposure to maximum rating conditions for extended periods may affect device reliability.

Table 9. Absolute maximum ratings

| Symbol | Ratings | Maximum value | Unit |
|---|---|---|---|
| Vdd | Supply voltage | -0.3 to 4.8 | V |
| Vdd_IO | I/O pins Supply voltage | -0.3 to 4.8 | V |
| Vin | Input voltage on any control pin (CS, SCL/SPC, SDA/SDI/SDO, SDO/SA0) | -0.3 to Vdd_IO +0.3 | V |
| APOW | Acceleration (any axis, powered, Vdd = 2.5 V) | 3000 g for 0.5 ms | |
| | | 10000 g for 0.2 ms  | |
| AUNP | Acceleration (any axis, unpowered) | 3000 g for 0.5 ms | |
| | | 10000 g for 0.2 ms  | |
| TOP | Operating temperature range | -40 to +85 | °C |
| TSTG | Storage temperature range | -40 to +125 | °C |
| ESD | Electrostatic discharge protection | 2 (HBM) | kV |

Note: Supply voltage on any pin should never exceed 4.8 V



This device is sensitive to mechanical shock, improper handling can cause permanent damage to the part.



This device is sensitive to electrostatic discharge (ESD), improper handling can cause permanent damage to the part.



### 3 Terminology and functionality

#### 3.1 Terminology

#### 3.1.1 Sensitivity

Sensitivity describes the gain of the sensor and can be determined, for example, by applying 1 g acceleration to it. As the sensor can measure DC accelerations this can be done easily by pointing the axis of interest towards the center of the Earth, noting the output value, rotating the sensor by 180 degrees (pointing to the sky) and noting the output value again. By doing so,  $\pm 1$  g acceleration is applied to the sensor. Subtracting the larger output value from the smaller one, and dividing the result by 2, leads to the actual sensitivity of the sensor. This value changes very little over temperature and also time. The sensitivity tolerance describes the range of sensitivities of a large population of sensors.

#### 3.1.2 Zero-g level

The zero-*g* level offset (TyOff) describes the deviation of an actual output signal from the ideal output signal if no acceleration is present. A sensor in a steady state on a horizontal surface measures 0 *g* for the X-axis and 0 *g* for the Y-axis whereas the Z-axis measures 1 *g*. The output is ideally in the middle of the dynamic range of the sensor (content of OUT registers 00h, data expressed as 2's complement number). A deviation from ideal value in this case is called Zero-*g* offset. Offset is to some extent a result of stress to MEMS sensor and therefore the offset can slightly change after mounting the sensor onto a printed circuit board or exposing it to extensive mechanical stress. Offset changes little over temperature, see *Table 4* "Zero-*g* level change vs. temperature" (TCOff). The zero-*g* level tolerance (TyOff) describes the standard deviation of the range of zero-*g* levels of a population of sensors.

### 3.2 Functionality

### 3.2.1 High-resolution, normal mode, low-power mode

LIS3DH provides three different operating modes: *high-resolution mode*, *normal mode* and *low-power mode*.

The table below summarizes how to select the operating mode.

Table 10. Operating mode selection

| Operating mode | CTRL_REG1[3]<br>(LPen bit) | CTRL_REG4[3]<br>(HR bit) | BW [Hz] | Turn-on<br>time [ms] | So @ ±2g<br>[mg/digit] |
|---|---|---|---|---|---|
| Low-power mode (8-bit data output) | 1 | 0 | ODR/2 | 1 | 16 |
| Normal mode<br>(10-bit data output) | 0 | 0 | ODR/2 | 1.6 | 4 |
| High-resolution mode (12-bit data output) | 0 | 1 | ODR/9 | 7/ODR | 1 |
| Not allowed | 1 | 1 | -- | -- | -- |

The turn-on time to transition to another operating mode is given in *Table 11*.

Table 11. Turn-on time for operating mode transition

| Operating mode change | Turn-on time<br>[ms] |
|---|---|
| 12-bit mode to 8-bit mode  | 1/ODR |
| 12-bit mode to 10-bit mode | 1/ODR |
| 10-bit mode to 8-bit mode  | 1/ODR |
| 10-bit mode to 12-bit mode | 7/ODR |
| 8-bit mode to 10-bit mode  | 1/ODR |
| 8-bit mode to 12-bit mode  | 7/ODR |

Table 12. Current consumption of operating modes

| Operating mode [Hz] | Low-power mode<br>(8-bit data output)<br>[µA] | Normal mode<br>(10-bit data output)<br>[µA] | High resolution<br>(12-bit data output)<br>[µA] |
|---|---|---|---|
| 1 | 2 | 2 | 2 |
| 10 | 3 | 4 | 4 |
| 25 | 4 | 6 | 6 |
| 50 | 6 | 11 | 11 |
| 100 | 10 | 20 | 20 |
| 200 | 18 | 38 | 38 |
| 400 | 36 | 73 | 73 |
| 1344 | -- | 185 | 185 |
| 1620 | 100 | -- | -- |
| 5376 | 185 | -- | -- |

#### 3.2.2 Self-test

The self-test allows the user to check the sensor functionality without moving it. The self-test function is off when the self-test bit (ST) is programmed to '0'. When the self-test bit is programmed to '1', an actuation force is applied to the sensor, simulating a definite input acceleration. In this case the sensor outputs exhibit a change in their DC levels which are related to the selected full scale through the device sensitivity. When the self-test is activated, the device output level is given by the algebraic sum of the signals produced by the acceleration acting on the sensor and by the electrostatic test-force. If the output signals change within the amplitude specified inside *Table 4*, then the sensor is working properly and the parameters of the interface chip are within the defined specifications.



#### 3.2.3 6D / 4D orientation detection

The LIS3DH provides the capability to detect the orientation of the device in space, enabling easy implementation of energy-saving procedures and automatic image rotation for mobile devices.

The 4D detection is a subset of the 6D function especially defined to be implemented in mobile devices for portrait and landscape computation. In 4D configuration, the Z-axis position detection is disabled.

#### 3.2.4 "Sleep-to-wake" and "Return-to-sleep"

The LIS3DH can be programmed to automatically switch to low-power mode upon recognition of a determined event.

Once the event condition is over, the device returns back to the preset normal or high-resolution mode.

To enable this function the desired threshold value must be stored inside the *ACT\_THS* (*3Eh*) register while the duration value is written inside the *ACT\_DUR* (*3Fh*) register.

When the acceleration falls below the threshold value, the device automatically switches to low-power mode (10 Hz ODR).

During this condition, the ODR[3:0] bits and the LPen bit inside *CTRL\_REG1* (20h) and the HR bit in *CTRL\_REG4* (23h) are not considered.

As soon as the acceleration rises above threshold, the module restores the operating mode and ODRs as determined by the CTRL\_REG1 (20h) and CTRL\_REG4 (23h) settings.

### 3.3 Sensing element

A proprietary process is used to create a surface micro-machined accelerometer. The technology allows carrying out suspended silicon structures which are attached to the substrate in a few points called anchors and are free to move in the direction of the sensed acceleration. To be compatible with the traditional packaging techniques a cap is placed on top of the sensing element to avoid blocking the moving parts during the moulding phase of the plastic encapsulation.

When an acceleration is applied to the sensor the proof mass displaces from its nominal position, causing an imbalance in the capacitive half-bridge. This imbalance is measured using charge integration in response to a voltage pulse applied to the capacitor.

At steady state the nominal value of the capacitors are few pF and when an acceleration is applied the maximum variation of the capacitive load is in the fF range.

#### 3.4 IC interface

The complete measurement chain is composed by a low-noise capacitive amplifier which converts the capacitive unbalancing of the MEMS sensor into an analog voltage that is finally available to the user by an analog-to-digital converter.

The acceleration data may be accessed through an I<sup>2</sup>C/SPI interface thus making the device particularly suitable for direct interfacing with a microcontroller.

577

The LIS3DH features a Data-Ready signal (DRDY) which indicates when a new set of measured acceleration data is available, thus simplifying data synchronization in the digital system that uses the device.

The LIS3DH may also be configured to generate an inertial wake-up and free-fall interrupt signal accordingly to a programmed acceleration event along the enabled axes. Both free-fall and wake-up can be available simultaneously on two different pins.

#### 3.5 Factory calibration

The IC interface is factory calibrated for sensitivity (So) and Zero-g level (TyOff).

The trim values are stored inside the device in non-volatile memory. Any time the device is turned on, these values are downloaded into the registers to be used during active operation. This allows using the device without further calibration.

#### 3.6 FIFO

The LIS3DH contains a 10-bit, 32-level FIFO. Buffered output allows 4 operation modes: FIFO, Stream, Stream-to-FIFO and FIFO bypass. When FIFO bypass mode is activated, FIFO is not operating and remains empty. In FIFO mode, measurement data from acceleration detection on the x, y, and z axes are stored in the FIFO buffer.

### 3.7 Auxiliary ADC and temperature sensor

The LIS3DH contains an auxiliary ADC with 3 separate dedicated inputs: pins ADC1, ADC2, ADC3.

The user can retrieve the converted data from registers  $OUT\_ADC1\_L$  (08h),  $OUT\_ADC1\_H$  (09h),  $OUT\_ADC2\_L$  (0Ah),  $OUT\_ADC2\_H$  (0Bh) and  $OUT\_ADC3\_L$  (0Ch),  $OUT\_ADC3\_H$  (0Dh).

In order to use the auxiliary ADC, the user must set the BDU bit (bit 7) to 1 in *CTRL\_REG4* (23h) and the ADC\_EN bit (bit 7) to 1 in *TEMP\_CFG\_REG* (1Fh). The ADC sampling frequency is the same as that of the ODR in *CTRL\_REG1* (20h).

The input range is 1200 mv ±400 mV and the data output is expressed in 2's complement left-aligned.

The ADC resolution is 10 bits if the LPen (bit 3) in *CTRL\_REG1 (20h)* is cleared (high-resolution / normal mode), otherwise, in low-power mode, the ADC resolution is 8-bit.

Channel 3 of the ADC can be connected to the temperature sensor by setting the TEMP\_EN bit (bit 6) to 1 in *TEMP\_CFG\_REG (1Fh)*. Refer to *Table 5: Temperature sensor characteristics* for the conversion factor.



Application hints LIS3DH

### 4 Application hints



Figure 5. LIS3DH electrical connections

The device core is supplied through the Vdd line while the I/O pads are supplied through the Vdd\_IO line. Power supply decoupling capacitors (100 nF ceramic, 10  $\mu$ F aluminum) should be placed as near as possible to pin 14 of the device (common design practice).

All the voltage and ground supplies must be present at the same time to have proper behavior of the IC (refer to *Figure 5*). It is possible to remove Vdd maintaining Vdd\_IO without blocking the communication bus, in this condition the measurement chain is powered off.

The functionality of the device and the measured acceleration data is selectable and accessible through the  $I^2C$  or SPI interfaces. When using the  $I^2C$ , CS must be tied high.

ADC1, ADC2 & ADC3 if not used can be left floating or connected to Vdd or GND.

The functions, the threshold and the timing of the two interrupt pins (INT1 and INT2) can be completely programmed by the user through the  $I^2C/SPI$  interface.

LIS3DH Application hints

Table 13. Internal pin status

| Pin# | Name | Function | Pin status |
|---|---|---|---|
| 1 | Vdd_IO | Power supply for I/O pins | |
| 2 | NC | Not connected | |
| 3 | NC | Not connected | |
| 4 | SCL<br>SPC | I <sup>2</sup> C serial clock (SCL)<br>SPI serial port clock (SPC) | Default: input high impedance |
| 5 | GND | 0 V supply | |
| 6 | SDA<br>SDI<br>SDO | I <sup>2</sup> C serial data (SDA) SPI serial data input (SDI) 3-wire interface serial data output (SDO) | Default: (SDA) input high impedance |
| 7 | SDO<br>SA0 | SPI serial data output (SDO) I <sup>2</sup> C less significant bit of the device address (SA0) | Default: input with internal pull-up <sup>(1)</sup> |
| 8 | CS | SPI enable I <sup>2</sup> C/SPI mode selection:  1: SPI idle mode / I <sup>2</sup> C communication enabled  0: SPI communication mode / I <sup>2</sup> C disabled | Default: input high impedance |
| 9 | INT2 | Inertial interrupt 2 | Default: push-pull output forced to GND |
| 10 | RES | Connect to GND | |
| 11 | INT1 | Inertial interrupt 1 | Default: push-pull output forced to GND |
| 12 | GND | 0 V supply | |
| 13 | ADC3 | Analog-to-digital converter input 3 | Default: input high impedance |
| 14 | Vdd | Power supply | |
| 15 | ADC2 | Analog-to-digital converter input 2 | Default: input high impedance |
| 16 | ADC1 | Analog-to-digital converter input 1 | Default: input high impedance |

<sup>1.</sup> In order to disable the internal pull-up on the SDO/SA0 pin, write 90h in  $CTRL\_REGO$  (1Eh).

### 4.1 Soldering information

The LGA package is compliant with the ECOPACK<sup>®</sup>, RoHS and "Green" standard. It is qualified for soldering heat resistance according to JEDEC J-STD-020.

Leave "Pin 1 Indicator" unconnected during soldering.

Land pattern and soldering recommendations are available at www.st.com.

Digital main blocks LIS3DH

### 5 Digital main blocks

#### **5.1 FIFO**

The LIS3DH embeds a 32-level FIFO for each of the three output channels, X, Y and Z.

This allows consistent power saving for the system, since the host processor does not need to continuously poll data from the sensor, but it can wake up only when needed and burst the significant data out from the FIFO.

In order to enable the FIFO buffer, the FIFO EN bit in CTRL REG5 (24h) must be set to '1'.

This buffer can work according to the following different modes: Bypass mode, FIFO mode, Stream mode and Stream-to-FIFO mode. Each mode is selected by the FM [1:0] bits in FIFO\_CTRL\_REG (2Eh). Programmable FIFO watermark level, FIFO empty or FIFO overrun events can be enabled to generate dedicated interrupts on the INT1 pin (configuration through CTRL\_REG3 (22h)).

In the FIFO\_SRC\_REG (2Fh) register the EMPTY bit is equal to '1' when all FIFO samples are ready and FIFO is empty.

In the FIFO\_SRC\_REG (2Fh) register the WTM bit goes to '1' if new data is written in the buffer and FIFO\_SRC\_REG (2Fh) (FSS [4:0]) is greater than or equal to FIFO\_CTRL\_REG (2Eh) (FTH [4:0]). FIFO\_SRC\_REG (2Fh) (WTM) goes to '0' if reading an X, Y, Z data slot from FIFO and FIFO\_SRC\_REG (2Fh) (FSS [4:0]) is less than or equal to FIFO\_CTRL\_REG (2Eh) (FTH [4:0]).

In the FIFO\_SRC\_REG (2Fh) register the OVRN\_FIFO bit is equal to '1' if the FIFO slot is overwritten.

#### 5.1.1 Bypass mode

In Bypass mode the FIFO is not operational and for this reason it remains empty. For each channel only the first address is used. The remaining FIFO levels are empty.

Bypass mode must be used in order to reset the FIFO buffer when a different mode is operating (i.e. FIFO mode).

#### 5.1.2 FIFO mode

In FIFO mode, the buffer continues filling data from the X, Y and Z accelerometer channels until it is full (a set of 32 samples stored). When the FIFO is full, it stops collecting data from the input channels and the FIFO content remains unchanged.

An overrun interrupt can be enabled, I1\_OVERRUN = '1' in the *CTRL\_REG3 (22h)* register, in order to be raised when the FIFO stops collecting data. When the overrun interrupt occurs, the first data has been overwritten and the FIFO stops collecting data from the input channels.

After the last read it is necessary to exit Bypass mode in order to reset the FIFO content. After this reset command, it is possible to restart FIFO mode just by selecting the FIFO mode configuration (FM[1:0] bits) in register FIFO\_CTRL\_REG (2Eh).

LIS3DH Digital main blocks

#### 5.1.3 Stream mode

In Stream mode the FIFO continues filling data from the X, Y, and Z accelerometer channels until the buffer is full (a set of 32 samples stored) at which point the FIFO buffer index restarts from the beginning and older data is replaced by the current data. The oldest values continue to be overwritten until a read operation frees the FIFO slots.

An overrun interrupt can be enabled, I1\_OVERRUN = '1' in the *CTRL\_REG3 (22h)* register, in order to read the entire contents of the FIFO at once. If, in the application, it is mandatory not to lose data and it is not possible to read at least one sample for each axis within one ODR period, a watermark interrupt can be enabled in order to read partially the FIFO and leave memory slots free for incoming data.

Setting the FTH [4:0] bit in the *FIFO\_CTRL\_REG* (2Eh) register to an N value, the number of X, Y and Z data samples that should be read at the rise of the watermark interrupt is up to (N+1).

#### 5.1.4 Stream-to-FIFO mode

In Stream-to-FIFO mode, data from the X, Y and Z accelerometer channels are collected in a combination of Stream mode and FIFO mode. The FIFO buffer starts operating in Stream mode and switches to FIFO mode when the selected interrupt occurs.

The FIFO operating mode changes according to the INT1 pin value if the TR bit is set to '0' in the FIFO\_CTRL\_REG (2Eh) register or the INT2 pin value if the TR bit is set to '1' in the FIFO\_CTRL\_REG (2Eh) register.

When the interrupt pin is selected and the interrupt event is configured on the corresponding pin, the FIFO operates in Stream mode if the pin value is equal to '0' and it operates in FIFO mode if the pin value is equal to '1'. Switching modes is dynamically performed according to the pin value.

Stream-to-FIFO can be used in order to analyze the sampling history that generates an interrupt. The standard operation is to read the contents of FIFO when the FIFO mode is triggered and the FIFO buffer is full and stopped.

#### 5.1.5 Retrieving data from FIFO

FIFO data is read from OUT\_X\_L (28h), OUT\_X\_H (29h), OUT\_Y\_L (2Ah), OUT\_Y\_H (2Bh) and OUT\_Z\_L (2Ch), OUT\_Z\_H (2Dh). When the FIFO is in Stream, Stream-to-FIFO or FIFO mode, a read operation from the OUT\_X\_L (28h), OUT\_X\_H (29h), OUT\_Y\_L (2Ah), OUT\_Y\_H (2Bh) or OUT\_Z\_L (2Ch), OUT\_Z\_H (2Dh) registers provides the data stored in the FIFO. Each time data is read from the FIFO, the oldest X, Y and Z data are placed in the OUT\_X\_L (28h), OUT\_X\_H (29h), OUT\_Y\_L (2Ah), OUT\_Y\_H (2Bh) and OUT\_Z\_L (2Ch), OUT\_Z\_H (2Dh) registers and both single read and read burst operations can be used.

The address to be read is automatically updated by the device and it rolls back to 0x28 when register 0x2D is reached. In order to read all FIFO levels in a multiple byte read, 192 bytes (6 output registers of 32 levels) have to be read.

Digital interfaces LIS3DH

### 6 Digital interfaces

The registers embedded inside the LIS3DH may be accessed through both the I<sup>2</sup>C and SPI serial interfaces. The latter may be SW configured to operate either in 3-wire or 4-wire interface mode.

The serial interfaces are mapped onto the same pads. To select/exploit the I<sup>2</sup>C interface, the CS line must be tied high (i.e. connected to Vdd\_IO).

| Pin name | Pin description |
|---|---|
| CS | SPI enable<br>I2C/SPI mode selection:<br>1: SPI idle mode / I2C communication enabled<br>0: SPI communication mode / I2C disabled |
| SCL | I2C serial clock (SCL) |
| SPC | SPI serial port clock (SPC) |
| SDA | I2C serial data (SDA) |
| SDI | SPI serial data input (SDI) |
| SDO | 3-wire interface serial data output (SDO) |
| SA0 | I2C less significant bit of the device address (SA0) |
| SDO | SPI serial data output (SDO) |

Table 14. Serial interface pin description

### 6.1 I<sup>2</sup>C serial interface

The LIS3DH  $I^2C$  is a bus slave. The  $I^2C$  is employed to write data into registers whose content can also be read back.

The relevant I<sup>2</sup>C terminology is given in the table below.

Term Description

Transmitter The device which sends data to the bus

Receiver The device which receives data from the bus

Master The device which initiates a transfer, generates clock signals and terminates a transfer

Slave The device addressed by the master

Table 15. I<sup>2</sup>C terminology

There are two signals associated with the I<sup>2</sup>C bus: the serial clock line (SCL) and the Serial DAta line (SDA). The latter is a bidirectional line used for sending and receiving the data to/from the interface. Both the lines must be connected to Vdd\_IO through external pull-up resistor. When the bus is free both the lines are high.

The  $I^2C$  interface is compliant with fast mode (400 kHz)  $I^2C$  standards as well as with normal mode.

LIS3DH Digital interfaces

#### 6.1.1 I<sup>2</sup>C operation

The transaction on the bus is started through a START (ST) signal. A START condition is defined as a HIGH-to-LOW transition on the data line while the SCL line is held HIGH. After this has been transmitted by the Master, the bus is considered busy. The next byte of data transmitted after the start condition contains the address of the slave in the first 7 bits and the eighth bit tells whether the Master is receiving data from the slave or transmitting data to the slave. When an address is sent, each device in the system compares the first seven bits after a start condition with its address. If they match, the device considers itself addressed by the Master.

The Slave ADdress (SAD) associated to the LIS3DH is 001100xb. The **SDO/SA0** pad can be used to modify the less significant bit of the device address. If the SA0 pad is connected to the voltage supply, LSb is '1' (address 0011001b) else if SA0 pad is connected to ground, the LSb value is '0' (address 0011000b). This solution permits to connect and address two different accelerometers to the same  $I^2C$  lines.

Data transfer with acknowledge is mandatory. The transmitter must release the SDA line during the acknowledge pulse. The receiver must then pull the data line LOW so that it remains stable low during the HIGH period of the acknowledge clock pulse. A receiver which has been addressed is obliged to generate an acknowledge after each byte of data received.

The I<sup>2</sup>C embedded inside the LIS3DH behaves like a slave device and the following protocol must be adhered to. After the start condition (ST) a slave address is sent, once a slave acknowledge (SAK) has been returned, an 8-bit sub-address (SUB) is transmitted: the 7 LSb represent the actual register address while the MSB enables address auto increment. If the MSb of the SUB field is '1', the SUB (register address) is automatically increased to allow multiple data read/writes.

The slave address is completed with a Read/Write bit. If the bit was '1' (Read), a repeated START (SR) condition must be issued after the two sub-address bytes; if the bit is '0' (Write) the Master transmit to the slave with direction unchanged. *Table 16* explains how the SAD+Read/Write bit pattern is composed, listing all the possible configurations.

Table 16. SAD+Read/Write patterns

| Command | SAD[6:1] | SAD[0] = SA0 | R/W | SAD+R/W |
|---|---|---|-----|---|
| Read | 001100 | 0 | 1 | 00110001 (31h) |
| Write | 001100 | 0 | 0 | 00110000 (30h) |
| Read | 001100 | 1 | 1 | 00110011 (33h) |
| Write | 001100 | 1 | 0 | 00110010 (32h) |

Table 17. Transfer when master is writing one byte to slave

| Master | ST | SAD + W | | SUB | | DATA | | SP |
|---|----|---|-----|-----|-----|---|-----|----|
| Slave  | | | SAK | | SAK | | SAK | |

Table 18. Transfer when master is writing multiple bytes to slave

| Master | ST | SAD + W | | SUB | | DATA | | DATA | | SP |
|---|----|---|-----|-----|-----|---|-----|---|-----|----|
| Slave  | | | SAK | | SAK | | SAK | | SAK | |



Digital interfaces LIS3DH

Table 19. Transfer when master is receiving (reading) one byte of data from slave

| Master | ST | SAD + W | | SUB | | SR | SAD + R | | | NMAK | SP |
|---|----|---|-----|-----|-----|----|---|-----|---|---|----|
| Slave  | | | SAK | | SAK | | | SAK | DATA | | |

Table 20. Transfer when master is receiving (reading) multiple bytes of data from slave

| Master | ST | SAD+W | | SUB | | SR | SAD+R | | | MAK | | MAK | | NMAK | SP |
|---|----|---|-----|-----|-----|----|---|-----|---|-----|---|-----|---|---|----|
| Slave  | | | SAK | | SAK | | | SAK | DATA | | DATA | | DATA | | |

Data are transmitted in byte format (DATA). Each data transfer contains 8 bits. The number of bytes transferred per transfer is unlimited. Data is transferred with the Most Significant bit (MSb) first. If a receiver can't receive another complete byte of data until it has performed some other function, it can hold the clock line, SCL LOW to force the transmitter into a wait state. Data transfer only continues when the receiver is ready for another byte and releases the data line. If a slave receiver doesn't acknowledge the slave address (i.e. it is not able to receive because it is performing some real-time function) the data line must be left HIGH by the slave. The Master can then abort the transfer. A LOW-to-HIGH transition on the SDA line while the SCL line is HIGH is defined as a STOP condition. Each data transfer must be terminated by the generation of a STOP (SP) condition.

In order to read multiple bytes, it is necessary to assert the most significant bit of the sub-address field. In other words, SUB(7) must be equal to 1 while SUB(6-0) represents the address of first register to be read.

In the presented communication format MAK is Master acknowledge and NMAK is No Master Acknowledge.

LIS3DH Digital interfaces

#### 6.2 SPI bus interface

The LIS3DH SPI is a bus slave. The SPI allows writing to and reading from the registers of the device.

The serial interface interacts with the application using 4 wires: CS, SPC, SDI and SDO.



Figure 6. Read and write protocol

**CS** is the serial port enable and it is controlled by the SPI master. It goes low at the start of the transmission and goes back high at the end. **SPC** is the serial port clock and it is controlled by the SPI master. It is stopped high when **CS** is high (no transmission). **SDI** and **SDO** are respectively the serial port data input and output. Those lines are driven at the falling edge of **SPC** and should be captured at the rising edge of **SPC**.

Both the read register and write register commands are completed in 16 clock pulses or in multiples of 8 in case of multiple read/write bytes. Bit duration is the time between two falling edges of **SPC**. The first bit (bit 0) starts at the first falling edge of **SPC** after the falling edge of **CS** while the last bit (bit 15, bit 23, ...) starts at the last falling edge of SPC just before the rising edge of **CS**.

**bit 0**: RW bit. When 0, the data DI(7:0) is written into the device. When 1, the data DO(7:0) from the device is read. In latter case, the chip drives **SDO** at the start of bit 8.

**bit 1**: MS bit. When 0, the address remains unchanged in multiple read/write commands. When 1, the address is auto incremented in multiple read/write commands.

bit 2-7: address AD(5:0). This is the address field of the indexed register.

bit 8-15: data DI(7:0) (write mode). This is the data that is written into the device (MSb first).

bit 8-15: data DO(7:0) (read mode). This is the data that is read from the device (MSb first).

In multiple read/write commands further blocks of 8 clock periods are added. When the MS bit is '0', the address used to read/write data remains the same for every block. When the MS bit is '1', the address used to read/write data is increased at every block.

The function and the behavior of SDI and SDO remain unchanged.

Digital interfaces LIS3DH

#### 6.2.1 SPI read

Figure 7. SPI read protocol



The SPI read command is performed with 16 clock pulses. A multiple byte read command is performed by adding blocks of 8 clock pulses to the previous one.

bit 0: READ bit. The value is 1.

**bit 1**:  $\overline{MS}$  bit. When 0, does not increment the address; when 1, increments the address in multiple reads.

bit 2-7: address AD(5:0). This is the address field of the indexed register.

bit 8-15: data DO(7:0) (read mode). This is the data that is read from the device (MSb first).

bit 16-...: data DO(...-8). Further data in multiple byte reads.

Figure 8. Multiple byte SPI read protocol (2-byte example)



LIS3DH Digital interfaces

#### 6.2.2 SPI write

Figure 9. SPI write protocol



The SPI write command is performed with 16 clock pulses. A multiple byte write command is performed by adding blocks of 8 clock pulses to the previous one.

bit 0: WRITE bit. The value is 0.

**bit 1**: MS bit. When 0, does not increment the address; when 1, increments the address in multiple writes.

bit 2 -7: address AD(5:0). This is the address field of the indexed register.

*bit 8-15*: data DI(7:0) (write mode). This is the data that is written inside the device (MSb first).

bit 16-...: data DI(...-8). Further data in multiple byte writes.

Figure 10. Multiple byte SPI write protocol (2-byte example)



Digital interfaces LIS3DH

#### 6.2.3 SPI read in 3-wire mode

3-wire mode is entered by setting the bit SIM (SPI serial interface mode selection) to '1' in CTRL REG4 (23h).

CS \_\_\_\_\_\_\_\_\_\_\_\_\_\_\_\_\_\_\_\_\_\_\_\_\_\_\_\_\_\_\_\_\_\_\_\_

Figure 11. SPI read protocol in 3-wire mode

The SPI read command is performed with 16 clock pulses:

bit 0: READ bit. The value is 1.

**bit 1**: MS bit. When 0, does not increment the address; when 1, increments the address in multiple reads.

bit 2-7: address AD(5:0). This is the address field of the indexed register.

*bit 8-15*: data DO(7:0) (read mode). This is the data that is read from the device (MSb first). The multiple read command is also available in 3-wire mode.

LIS3DH Register mapping

## 7 Register mapping

The table given below provides a list of the 8-bit registers embedded in the device and the corresponding addresses.

Table 21. Register address map

| Name | Type | Register address | | Default  | Comment |
|---|---|---|---|---|---|
| | | Hex | Binary | | |
| Reserved (do not modify) | | 00 - 06 | | | Reserved |
| STATUS_REG_AUX | r | 07 | 000 0111 | Output | |
| OUT_ADC1_L | r | 08 | 000 1000 | Output | |
| OUT_ADC1_H | r | 09 | 000 1001 | Output | |
| OUT_ADC2_L | r | 0A | 000 1010 | Output | |
| OUT_ADC2_H | r | 0B | 000 1011 | Output | |
| OUT_ADC3_L | r | 0C | 000 1100 | Output | |
| OUT_ADC3_H | r | 0D | 000 1101 | Output | |
| Reserved (do not modify) | | 0E | | | Reserved |
| WHO_AM_I | r | 0F | 000 1111 | 00110011 | Dummy register |
| Reserved (do not modify) | | 10 - 1D | | | Reserved |
| CTRL_REG0 | rw | 1E | 001 1110 | 00010000 | |
| TEMP_CFG_REG | rw | 1F | 001 1111 | 00000000 | |
| CTRL_REG1 | rw | 20 | 010 0000 | 00000111 | |
| CTRL_REG2 | rw | 21 | 010 0001 | 00000000 | |
| CTRL_REG3 | rw | 22 | 010 0010 | 00000000 | |
| CTRL_REG4 | rw | 23 | 010 0011 | 00000000 | |
| CTRL_REG5 | rw | 24 | 010 0100 | 00000000 | |
| CTRL_REG6 | rw | 25 | 010 0101 | 00000000 | |
| REFERENCE | rw | 26 | 010 0110 | 00000000 | |
| STATUS_REG | r | 27 | 010 0111 | Output | |
| OUT_X_L | r | 28 | 010 1000 | Output | |
| OUT_X_H | r | 29 | 010 1001 | Output | |
| OUT_Y_L | r | 2A | 010 1010 | Output | |
| OUT_Y_H | r | 2B | 010 1011 | Output | |
| OUT_Z_L | r | 2C | 010 1100 | Output | |
| OUT_Z_H | r | 2D | 010 1101 | Output | |
| FIFO_CTRL_REG | rw | 2E | 010 1110 | 00000000 | |
| FIFO_SRC_REG | r | 2F | 010 1111 | Output | |
| Name | Type | Register address | | Default  | Comment |
| | | Hex | Binary | | |
| INT1_CFG | rw | 30 | 011 0000 | 00000000 | |
| INT1_SRC | r | 31 | 011 0001 | Output | |
| INT1_THS | rw | 32 | 011 0010 | 00000000 | |
| INT1_DURATION | rw | 33 | 011 0011 | 00000000 | |
| INT2_CFG | rw | 34 | 011 0100 | 00000000 | |
| INT2_SRC | r | 35 | 011 0101 | Output | |
| INT2_THS | rw | 36 | 011 0110 | 00000000 | |
| INT2_DURATION | rw | 37 | 011 0111 | 00000000 | |
| CLICK_CFG | rw | 38 | 011 1000 | 00000000 | |
| CLICK_SRC | r | 39 | 011 1001 | Output | |
| CLICK_THS | rw | 3A | 011 1010 | 00000000 | |
| TIME_LIMIT | rw | 3B | 011 1011 | 00000000 | |
| TIME_LATENCY | rw | 3C | 011 1100 | 00000000 | |
| TIME_WINDOW | rw | 3D | 011 1101 | 00000000 | |
| ACT_THS | rw | 3E | 011 1110 | 00000000 | |
| ACT_DUR | rw | 3F | 011 1111 | 00000000 | |

Register mapping LIS3DH

Table 21. Register address map

Registers marked as *Reserved* or not listed in the table above must not be changed. Writing to those registers may cause permanent damage to the device.

The content of the registers that are loaded at boot should not be changed. They contain the factory calibration values. Their content is automatically restored when the device is powered up.

The boot procedure is complete about 5 milliseconds after device power-up.

### 8 Registers description

### 8.1 STATUS\_REG\_AUX (07h)

#### Table 22. STATUS\_REG\_AUX register

| 3210R | 30R | 20R | 10R | 321DA | 3DA | 2DA | 1DA |
|---|-----|-----|-----|---|-----|-----|-----|
|-------|-----|-----|-----|-------|-----|-----|-----|

#### Table 23. STATUS\_REG\_AUX description

| 321OR | 1, 2 and 3-axis data overrun. Default value: 0<br>(0: no overrun has occurred; 1: a new set of data has overwritten the previous set) |
|---|---|
| 3OR | 3-axis data overrun. Default value: 0<br>(0: no overrun has occurred;<br>1: new data for the 3-axis has overwritten the previous data) |
| 2OR | 2-axis data overrun. Default value: 0<br>(0: no overrun has occurred;<br>1: new data for the 2-axis has overwritten the previous data) |
| 1OR | 1-axis data overrun. Default value: 0<br>(0: no overrun has occurred;<br>1: new data for the 1-axis has overwritten the previous data) |
| 321DA | 1, 2 and 3-axis new data available. Default value: 0<br>(0: a new set of data is not yet available; 1: a new set of data is available) |
| 3DA | 3-axis new data available. Default value: 0<br>(0: new data for the 3-axis is not yet available;<br>1: new data for the 3-axis is available) |
| 2DA | 2-axis new data available. Default value: 0<br>(0: new data for the 2-axis is not yet available;<br>1: new data for the 2-axis is available) |
| 1DA | 1-axis new data available. Default value: 0<br>(0: new data for the 1-axis is not yet available;<br>1: new data for the 1-axis is available) |

### 8.2 OUT\_ADC1\_L (08h), OUT\_ADC1\_H (09h)

Auxiliary 10-bit ADC channel 1 conversion. For auxiliary ADC setting refer to Section 3.7: Auxiliary ADC and temperature sensor.

### 8.3 OUT\_ADC2\_L (0Ah), OUT\_ADC2\_H (0Bh)

Auxiliary 10-bit ADC channel 2 conversion. For auxiliary ADC setting refer to Section 3.7: Auxiliary ADC and temperature sensor.

### 8.4 OUT\_ADC3\_L (0Ch), OUT\_ADC3\_H (0Dh)

Auxiliary 10-bit ADC channel 3 conversion or temperature sensor data output. Refer to Section 3.7: Auxiliary ADC and temperature sensor.



Registers description LIS3DH

### 8.5 WHO\_AM\_I (0Fh)

#### Table 24. WHO\_AM\_I register

| 0 | 0 | 1 | 1 | 0 | 0 | 1 | 1 |
|---|---|---|---|---|---|---|---|
|---|---|---|---|---|---|---|---|

Device identification register.

### 8.6 CTRL\_REG0 (1Eh)

#### Table 25. CTRL\_REG0 register

| SDO_PU_DISC | 0(1) | 0(1) | 1(2) | 0(1) | 0(1) | 0(1) | 0(1) |
|---|---|---|---|---|---|---|---|
|-------------|------|------|------|------|------|------|------|

- 1. This bit must be set to 0 for correct operation of the device.
- 2. This bit must be set to 1 for correct operation of the device.

#### Table 26. CTRL\_REG0 description

| SDO_PU_DISC | Disconnect SDO/SA0 pull-up. Default value: 00010000<br>(0: pull-up connected to SDO/SA0 pin;<br>1: pull-up disconnected to SDO/SA0 pin) |
|---|---|
|-------------|-----------------------------------------------------------------------------------------------------------------------------------------|

Note: Leave bits 0 through 6 at the default value in order to ensure correct operation of the device.

### 8.7 TEMP\_CFG\_REG (1Fh)

#### Table 27. TEMP\_CFG\_REG register

| ADC_EN | TEMP_EN | 0 | 0 | 0 | 0 | 0 | 0 |
|---|---|---|---|---|---|---|---|
|--------|---------|---|---|---|---|---|---|

#### Table 28. TEMP\_CFG\_REG description

| TEMP_EN | Temperature sensor (T) enable. Default value: 0 (0: T disabled; 1: T enabled) |
|---|---|
| ADC_EN  | ADC enable. Default value: 0 (0: ADC disabled; 1: ADC enabled) |

### 8.8 CTRL\_REG1 (20h)

#### Table 29. CTRL\_REG1 register

| ODR3 | ODR2 | ODR1 | ODR0 | LPen | Zen | Yen | Xen |
|---|---|---|---|---|-----|-----|-----|
|------|------|------|------|------|-----|-----|-----|

#### Table 30. CTRL\_REG1 description

| ODR[3:0] | Data rate selection. Default value: 0000<br>(0000: power-down mode; others: Refer to <i>Table 31: Data rate configuration</i> ) |
|---|---|
| LPen | Low-power mode enable. Default value: 0<br>(0: high-resolution mode / normal mode, 1: low-power mode)<br>(Refer to section <i>Section 3.2.1: High-resolution, normal mode, low-power mode</i> ) |
| Zen | Z-axis enable. Default value: 1<br>(0: Z-axis disabled; 1: Z-axis enabled) |
| Yen | Y-axis enable. Default value: 1<br>(0: Y-axis disabled; 1: Y-axis enabled) |
| Xen | X-axis enable. Default value: 1<br>(0: X-axis disabled; 1: X-axis enabled) |

**ODR[3:0]** is used to set the power mode and ODR selection. The following table indicates the frequency of each combination of ODR[3:0].

Table 31. Data rate configuration

| ODR3 | ODR2 | ODR1 | ODR0 | Power mode selection |
|---|---|---|---|---|
| 0 | 0 | 0 | 0 | Power-down mode |
| 0 | 0 | 0 | 1 | HR / Normal / Low-power mode (1 Hz) |
| 0 | 0 | 1 | 0 | HR / Normal / Low-power mode (10 Hz) |
| 0 | 0 | 1 | 1 | HR / Normal / Low-power mode (25 Hz) |
| 0 | 1 | 0 | 0 | HR / Normal / Low-power mode (50 Hz) |
| 0 | 1 | 0 | 1 | HR / Normal / Low-power mode (100 Hz) |
| 0 | 1 | 1 | 0 | HR / Normal / Low-power mode (200 Hz) |
| 0 | 1 | 1 | 1 | HR / Normal / Low-power mode (400 Hz) |
| 1 | 0 | 0 | 0 | Low power mode (1.60 kHz) |
| 1 | 0 | 0 | 1 | HR / normal (1.344 kHz);<br>Low-power mode (5.376 kHz) |



Registers description LIS3DH

### 8.9 CTRL\_REG2 (21h)

#### Table 32. CTRL\_REG2 register

| HPM1 | HPM0 | HPCF2 | HPCF1 | FDS | HPCLICK | HP_IA2 | HP_IA1 |
|---|---|---|---|-----|---|---|---|
|------|------|-------|-------|-----|---------|--------|--------|

#### Table 33. CTRL\_REG2 description

| HPM[1:0]  | High-pass filter mode selection. Default value: 00<br>Refer to Table 34: High-pass filter mode configuration |
|---|---|
| HPCF[2:1] | High-pass filter cutoff frequency selection |
| FDS | Filtered data selection. Default value: 0<br>(0: internal filter bypassed;<br>1: data from internal filter sent to output register and FIFO) |
| HPCLICK | High-pass filter enabled for CLICK function.<br>(0: filter bypassed; 1: filter enabled) |
| HP_IA2 | High-pass filter enabled for AOI function on interrupt 2,<br>(0: filter bypassed; 1: filter enabled) |
| HP_IA1 | High-pass filter enabled for AOI function on interrupt 1,<br>(0: filter bypassed; 1: filter enabled) |

#### Table 34. High-pass filter mode configuration

| HPM1 | HPM0 | High-pass filter mode |
|---|---|---|
| 0 | 0 | Normal mode (reset by reading <i>REFERENCE (26h)</i> ) |
| 0 | 1 | Reference signal for filtering |
| 1 | 0 | Normal mode |
| 1 | 1 | Autoreset on interrupt event |

### 8.10 CTRL\_REG3 (22h)

#### Table 35. CTRL\_REG3 register

| I1_CLICK | I1_IA1 | I1_IA2 | I1_ZYXDA | I1_321DA | I1_WTM | I1_OVERRUN | -- |
|---|---|---|---|---|---|---|----|
|----------|--------|--------|----------|----------|--------|------------|----|

#### Table 36. CTRL\_REG3 description

| I1_CLICK | Click interrupt on INT1. Default value: 0 (0: disable; 1: enable) |
|---|---|
| I1_IA1 | IA1 interrupt on INT1. Default value: 0 (0: disable; 1: enable) |
| I1_IA2 | IA2 interrupt on INT1. Default value: 0 (0: disable; 1: enable) |
| I1_ZYXDA | ZYXDA interrupt on INT1. Default value: 0 (0: disable; 1: enable) |
| I1_321DA | 321DA interrupt on INT1. Default value: 0 (0: disable; 1: enable) |
| I1_WTM | FIFO watermark interrupt on INT1. Default value: 0 (0: disable; 1: enable) |
| I1_OVERRUN | FIFO overrun interrupt on INT1. Default value: 0 (0: disable; 1: enable) |



### 8.11 CTRL\_REG4 (23h)

#### Table 37. CTRL\_REG4 register

| BDU | BLE(1) | FS1 | FS0 | HR | ST1 | ST0 | SIM |
|-----|---|-----|-----|----|-----|-----|-----|
|-----|--------|-----|-----|----|-----|-----|-----|

<sup>1.</sup> The BLE function can be activated only in high-resolution mode.

#### Table 38. CTRL\_REG4 description

| BDU | Block data update. Default value: 0<br>(0: continuous update;<br>1: output registers not updated until MSB and LSB reading) |
|---|---|
| BLE | Big/little endian data selection. Default value: 0<br>(0: Data LSB @ lower address; 1: Data MSB @ lower address) |
| FS[1:0] | Full-scale selection. Default value: 00<br>(00: ±2 <i>g</i> ; 01: ±4 <i>g</i> ; 10: ±8 <i>g</i> ; 11: ±16 <i>g</i> ) |
| HR | High-resolution output mode. Default value: 0<br>(0: high-resolution disabled; 1: high-resolution enabled) |
| ST[1:0] | Self-test enable. Default value: 00<br>(00: self-test disabled; other: See <i>Table 39</i> ) |
| SIM | SPI serial interface mode selection. Default value: 0<br>(0: 4-wire interface; 1: 3-wire interface) |

#### Table 39. Self-test mode configuration

| ST1 | ST0 | Self test mode |
|-----|-----|---|
| 0 | 0 | Normal mode |
| 0 | 1 | Self-test 0 |
| 1 | 0 | Self-test 1 |
| 1 | 1 | -- |



Registers description LIS3DH

### 8.12 CTRL\_REG5 (24h)

#### Table 40. CTRL\_REG5 register

| BOOT | FIFO_EN | -- | -- | LIR_INT1 | D4D_INT1 | LIR_INT2 | D4D_INT2 |
|---|---|----|----|---|---|---|---|
|------|---------|----|----|----------|----------|----------|----------|

#### Table 41. CTRL\_REG5 description

| BOOT | Reboot memory content. Default value: 0<br>(0: normal mode; 1: reboot memory content) |
|---|---|
| FIFO_EN  | FIFO enable. Default value: 0<br>(0: FIFO disable; 1: FIFO enable) |
| LIR_INT1 | Latch interrupt request on <i>INT1_SRC</i> register, with <i>INT1_SRC (31h)</i> register cleared by reading <i>INT1_SRC (31h)</i> itself. Default value: 0.<br>(0: interrupt request not latched; 1: interrupt request latched) |
| D4D_INT1 | 4D enable: 4D detection is enabled on INT1 when 6D bit on <i>INT1_CFG</i> is set to 1. |
| LIR_INT2 | Latch interrupt request on <i>INT2_SRC (35h)</i> register, with <i>INT2_SRC (35h)</i> register cleared by reading <i>INT2_SRC (35h)</i> itself. Default value: 0.<br>(0: interrupt request not latched; 1: interrupt request latched) |
| D4D_INT2 | 4D enable: 4D detection is enabled on INT2 pin when 6D bit on <i>INT2_CFG (34h)</i> is set to 1. |

### 8.13 CTRL\_REG6 (25h)

#### Table 42. CTRL\_REG6 register

| I2_CLICK | I2_IA1 | I2_IA2 | I2_BOOT | I2_ACT | - - | INT_POLARITY | - |
|---|---|---|---|---|-----|---|---|
| | | | | | | | |

#### Table 43. CTRL\_REG6 description

| I2_CLICK | Click interrupt on INT2 pin. Default value: 0<br>(0: disabled; 1: enabled) |
|---|---|
| I2_IA1 | Enable interrupt 1 function on INT2 pin. Default value: 0<br>(0: function disabled; 1: function enabled) |
| I2_IA2 | Enable interrupt 2 function on INT2 pin. Default value: 0<br>(0: function disabled; 1: function enabled) |
| I2_BOOT | Enable boot on INT2 pin. Default value: 0<br>(0: disabled; 1: enabled) |
| I2_ACT | Enable activity interrupt on INT2 pin. Default value: 0<br>(0: disabled; 1: enabled) |
| INT_POLARITY | INT1 and INT2 pin polarity. Default value: 0<br>(0: active-high; 1: active-low) |

### 8.14 REFERENCE (26h)

#### Table 44. REFERENCE register

| Ref7 | Ref6 | Ref5 | Ref4 | Ref3 | Ref2 | Ref1 | Ref0 |
|---|---|---|---|---|---|---|---|
|------|------|------|------|------|------|------|------|

#### Table 45. REFERENCE register description

| Ref[7:0] | Reference value for Interrupt generation. Default value: 0000 0000 |
|---|---|
|----------|--------------------------------------------------------------------|

### 8.15 STATUS\_REG (27h)

#### Table 46. STATUS register

| ZYXOR | ZOR | YOR | XOR | ZYXDA | ZDA | YDA | XDA |
|---|-----|-----|-----|---|-----|-----|-----|
|-------|-----|-----|-----|-------|-----|-----|-----|

#### Table 47. STATUS register description

| ZYXOR | X, Y and Z-axis data overrun. Default value: 0 (0: no overrun has occurred; 1: a new set of data has overwritten the previous set) |
|---|---|
| ZOR | Z-axis data overrun. Default value: 0<br>(0: no overrun has occurred;<br>1: a new data for the Z-axis has overwritten the previous data) |
| YOR | Y-axis data overrun. Default value: 0<br>(0: no overrun has occurred;<br>1: new data for the Y-axis has overwritten the previous data) |
| XOR | X-axis data overrun. Default value: 0<br>(0: no overrun has occurred;<br>1: new data for the X-axis has overwritten the previous data) |
| ZYXDA | X, Y and Z-axis new data available. Default value: 0 (0: a new set of data is not yet available; 1: a new set of data is available) |
| ZDA | Z-axis new data available. Default value: 0<br>(0: new data for the Z-axis is not yet available;<br>1: new data for the Z-axis is available) |
| YDA | Y-axis new data available. Default value: 0<br>(0: new data for the Y-axis is not yet available;<br>1: new data for the Y-axis is available) |



Registers description LIS3DH

### 8.16 OUT\_X\_L (28h), OUT\_X\_H (29h)

X-axis acceleration data. The value is expressed as two's complement left-justified. Please refer to Section 3.2.1: High-resolution, normal mode, low-power mode.

### 8.17 OUT\_Y\_L (2Ah), OUT\_Y\_H (2Bh)

Y-axis acceleration data. The value is expressed as two's complement left-justified. Please refer to Section 3.2.1: High-resolution, normal mode, low-power mode.

### 8.18 OUT\_Z\_L (2Ch), OUT\_Z\_H (2Dh)

Z-axis acceleration data. The value is expressed as two's complement left-justified. Please refer to Section 3.2.1: High-resolution, normal mode, low-power mode.

### 8.19 FIFO\_CTRL\_REG (2Eh)

#### Table 48. REFERENCE register

| FM1 | FM0 | TR | FTH4 | FTH3 | FTH2 | FTH1 | FTH0 |
|-----|-----|----|---|---|---|---|---|
|-----|-----|----|------|------|------|------|------|

#### Table 49. REFERENCE register description

| FM[1:0]  | FIFO mode selection. Default value: 00 (see Table 50) |
|---|---|
| TR | Trigger selection. Default value: 0 (0: trigger event allows triggering signal on INT1 1: trigger event allows triggering signal on INT2) |
| FTH[4:0] | Default value: 00000 |

#### Table 50. FIFO mode configuration

| FM1 | FM0 | Self test mode |
|-----|-----|---|
| 0 | 0 | Bypass mode |
| 0 | 1 | FIFO mode |
| 1 | 0 | Stream mode |
| 1 | 1 | Stream-to-FIFO |

### 8.20 FIFO\_SRC\_REG (2Fh)

#### Table 51. FIFO\_SRC\_REG register

| WTM | OVRN_FIFO | EMPTY | FSS4 | FSS3 | FSS2 | FSS1 | FSS0 |
|-----|---|---|---|---|---|---|---|
|-----|-----------|-------|------|------|------|------|------|

#### Table 52. FIFO\_SRC\_REG description

| Field | Description |
|---|---|
| WTM | WTM bit is set high when FIFO content exceeds watermark level |
| OVRN_FIFO | OVRN bit is set high when FIFO buffer is full; this means that the FIFO buffer contains 32 unread samples. At the following ODR a new sample set replaces the oldest FIFO value. The OVRN bit is set to 0 when the first sample set has been read |
| EMPTY | EMPTY flag is set high when all FIFO samples have been read and FIFO is empty |
| FSS [4:0] | FSS [4:0] field always contains the current number of unread samples stored in the FIFO buffer. When FIFO is enabled, this value increases at ODR frequency until the buffer is full, whereas, it decreases every time one sample set is retrieved from FIFO. |

### 8.21 INT1\_CFG (30h)

#### Table 53. INT1\_CFG register

| AOI | 6D | ZHIE | ZLIE | YHIE | YLIE | XHIE | XLIE |
|-----|----|---|---|---|---|---|---|
|-----|----|------|------|------|------|------|------|

#### Table 54. INT1\_CFG description

| Name | Description |
|---|---|
| AOI  | And/Or combination of Interrupt events. Default value: 0. Refer to Table 55: Interrupt mode |
| 6D | 6 direction detection function enabled. Default value: 0. Refer to Table 55: Interrupt mode |
| ZHIE | Enable interrupt generation on Z high event or on Direction recognition. Default value: 0 (0: disable interrupt request;1: enable interrupt request) |
| ZLIE | Enable interrupt generation on Z low event or on Direction recognition. Default value: 0 (0: disable interrupt request;1: enable interrupt request) |
| YHIE | Enable interrupt generation on Y high event or on Direction recognition. Default value: 0 (0: disable interrupt request; 1: enable interrupt request.) |
| YLIE | Enable interrupt generation on Y low event or on Direction recognition. Default value: 0 (0: disable interrupt request; 1: enable interrupt request.)  |
| XHIE | Enable interrupt generation on X high event or on Direction recognition. Default value: 0 (0: disable interrupt request; 1: enable interrupt request.) |
| XLIE | Enable interrupt generation on X low event or on Direction recognition. Default value: 0 (0: disable interrupt request; 1: enable interrupt request.)  |

Content of this register is loaded at boot.

Registers description LIS3DH

Write operation at this address is possible only after system boot.

Table 55. Interrupt mode

| AOI | 6D | Interrupt mode |
|-----|----|---|
| 0 | 0  | OR combination of interrupt events  |
| 0 | 1  | 6-direction movement recognition |
| 1 | 0  | AND combination of interrupt events |
| 1 | 1  | 6-direction position recognition |

Difference between AOI-6D = '01' and AOI-6D = '11'.

AOI-6D = '01' is movement recognition. An interrupt is generated when the orientation moves from an unknown zone to known zone. The interrupt signal remains for a duration ODR.

AOI-6D = '11' is direction recognition. An interrupt is generated when the orientation is inside a known zone. The interrupt signal remains until the orientation is inside the zone.

### 8.22 INT1\_SRC (31h)

Table 56. INT1\_SRC register

| 0 | IA | ZH | ZL | YH | YL | XH | XL |
|---|----|----|----|----|----|----|----|
|---|----|----|----|----|----|----|----|

Table 57. INT1\_SRC description

| IA | Interrupt active. Default value: 0<br>(0: no interrupt has been generated; 1: one or more interrupts have been generated) |
|----|---|
| ZH | Z high. Default value: 0<br>(0: no interrupt, 1: Z high event has occurred) |
| ZL | Z low. Default value: 0<br>(0: no interrupt; 1: Z low event has occurred) |
| YH | Y high. Default value: 0<br>(0: no interrupt, 1: Y high event has occurred) |
| YL | Y low. Default value: 0<br>(0: no interrupt, 1: Y low event has occurred) |
| XH | X high. Default value: 0<br>(0: no interrupt, 1: X high event has occurred) |
| XL | X low. Default value: 0<br>(0: no interrupt, 1: X low event has occurred) |

Interrupt 1 source register. Read-only register.

Reading at this address clears the *INT1\_SRC* (31h) IA bit (and the interrupt signal on the INT 1 pin) and allows the refresh of data in *INT1\_SRC* (31h) if the latched option was chosen.

### 8.23 INT1\_THS (32h)

#### Table 58. INT1\_THS register

| 0 | THS6 | THS5 | THS4 | THS3 | THS2 | THS1 | THS0 |
|---|---|---|---|---|---|---|---|
|---|------|------|------|------|------|------|------|

#### Table 59. INT1\_THS description

| THS[6:0] | Interrupt 1 threshold. Default value: 000 0000<br>1 LSb = 16 mg @ $FS = ±2 g$<br>1 LSb = 32 mg @ $FS = ±4 g$<br>1 LSb = 62 mg @ $FS = ±8 g$<br>1 LSb = 186 mg @ $FS = ±16 g$ |
|---|---|
|----------|------------------------------------------------------------------------------------------------------------------------------------------------------------------------------|

### 8.24 **INT1\_DURATION** (33h)

#### Table 60. INT1\_DURATION register

| 0 | D6 | D5 | D4 | D3 | D2 | D1 | D0 |
|---|----|----|----|----|----|----|----|
|---|----|----|----|----|----|----|----|

#### Table 61. INT1\_DURATION description

| D[6:0] | Duration value. Default value: 000 0000<br>1 LSb = 1/ODR |
|---|---|
|--------|----------------------------------------------------------|

The **D[6:0]** bits set the minimum duration of the Interrupt 2 event to be recognized. Duration steps and maximum values depend on the ODR chosen.

Duration time is measured in N/ODR, where N is the content of the duration register.

Registers description LIS3DH

### 8.25 INT2\_CFG (34h)

#### Table 62. INT2\_CFG register

| AOI | 6D | ZHIE | ZLIE | YHIE | YLIE | XHIE | XLIE |
|-----|----|---|---|---|---|---|---|
|-----|----|------|------|------|------|------|------|

#### Table 63. INT2\_CFG description

| AOI  | AND/OR combination of interrupt events. Default value: 0<br>(see <i>Table 64</i> ) |
|---|---|
| 6D | 6-direction detection function enabled. Default value: 0. Refer to <i>Table 64</i> . |
| ZHIE | Enable interrupt generation on Z high event. Default value: 0<br>(0: disable interrupt request;<br>1: enable interrupt request on measured accel. value higher than preset threshold) |
| ZLIE | Enable interrupt generation on Z low event. Default value: 0<br>(0: disable interrupt request;<br>1: enable interrupt request on measured accel. value lower than preset threshold) |
| YHIE | Enable interrupt generation on Y high event. Default value: 0<br>(0: disable interrupt request;<br>1: enable interrupt request on measured accel. value higher than preset threshold) |
| YLIE | Enable interrupt generation on Y low event. Default value: 0<br>(0: disable interrupt request;<br>1: enable interrupt request on measured accel. value lower than preset threshold) |
| XHIE | Enable interrupt generation on X high event. Default value: 0<br>(0: disable interrupt request;<br>1: enable interrupt request on measured accel. value higher than preset threshold) |
| XLIE | Enable interrupt generation on X low event. Default value: 0<br>(0: disable interrupt request;<br>1: enable interrupt request on measured accel. value lower than preset threshold) |

The content of this register is loaded at boot.

A write operation to this address is possible only after system boot.

Table 64. Interrupt mode

| AOI | 6D | Interrupt mode |
|-----|----|---|
| 0 | 0  | OR combination of interrupt events  |
| 0 | 1  | 6-direction movement recognition |
| 1 | 0  | AND combination of interrupt events |
| 1 | 1  | 6-direction position recognition |

The difference between AOI-6D = '01' and AOI-6D = '11'.

AOI-6D = '01' is movement recognition. An interrupt is generated when the orientation moves from an unknown zone to a known zone. The interrupt signal remains for a duration ODR.

AOI-6D = '11' is direction recognition. An interrupt is generated when the orientation is inside a known zone. The interrupt signal remains while the orientation is inside the zone.



### 8.26 INT2\_SRC (35h)

#### Table 65. INT2\_SRC register

| 0 | IA | ZH | ZL | YH | YL | XH | XL |
|---|----|----|----|----|----|----|----|
|---|----|----|----|----|----|----|----|

#### Table 66. INT2\_SRC description

| IA | Interrupt active. Default value: 0<br>(0: no interrupt has been generated; 1: one or more interrupts have been generated) |
|----|---|
| ZH | Z high. Default value: 0<br>(0: no interrupt, 1: Z high event has occurred) |
| ZL | Z low. Default value: 0<br>(0: no interrupt; 1: Z low event has occurred) |
| YH | Y high. Default value: 0<br>(0: no interrupt, 1: Y high event has occurred) |
| YL | Y low. Default value: 0<br>(0: no interrupt, 1: Y low event has occurred) |
| XH | X high. Default value: 0<br>(0: no interrupt, 1: X high event has occurred) |
| XL | X low. Default value: 0<br>(0: no interrupt, 1: X low event has occurred) |

Interrupt 2 source register. Read-only register.

Reading at this address clears the *INT2\_SRC* (35h) IA bit (and the interrupt signal on the INT2 pin) and allows the refresh of data in the *INT2\_SRC* (35h) register if the latched option was chosen.

### 8.27 INT2\_THS (36h)

#### Table 67. INT2\_THS register

| 0 | THS6 | THS5 | THS4 | THS3 | THS2 | THS1 | THS0 |
|---|---|---|---|---|---|---|---|
|---|------|------|------|------|------|------|------|

#### Table 68. INT2\_THS description

| THS[6:0] | Interrupt 2 threshold. Default value: 000 0000<br><br>1 LSb = 16 mg @ FS = ±2 g<br>1 LSb = 32 mg @ FS = ±4 g<br>1 LSb = 62 mg @ FS = ±8 g<br>1 LSb = 186 mg @ FS = ±16 g |
|---|---|
|----------|--------------------------------------------------------------------------------------------------------------------------------------------------------------------------|



Registers description LIS3DH

### 8.28 **INT2\_DURATION** (37h)

#### Table 69. INT2\_DURATION register

| 0 | D6 | D5 | D4 | D3 | D2 | D1 | D0 |
|---|----|----|----|----|----|----|----|
|---|----|----|----|----|----|----|----|

#### Table 70. INT2\_DURATION description

| D[6:0] | Duration value. Default value: 000 0000<br>1 LSb = 1/ODR(1) |
|---|---|

<sup>1.</sup> Duration time is measured in N/ODR, where N is the content of the duration register.

The **D[6:0]** bits set the minimum duration of the Interrupt 2 event to be recognized. Duration time steps and maximum values depend on the ODR chosen.

### 8.29 CLICK\_CFG (38h)

#### Table 71. CLICK\_CFG register

| -- | -- | zd | zs | yd | ys | xd | xs |
|----|----|----|----|----|----|----|----|
|----|----|----|----|----|----|----|----|

#### Table 72. CLICK\_CFG description

| ZD | Enable interrupt double click on Z-axis. Default value: 0<br>(0: disable interrupt request;<br>1: enable interrupt request on measured accel. value higher than preset threshold) |
|----|---|
| ZS | Enable interrupt single click on Z-axis. Default value: 0<br>(0: disable interrupt request;<br>1: enable interrupt request on measured accel. value higher than preset threshold) |
| YD | Enable interrupt double click on Y-axis. Default value: 0<br>(0: disable interrupt request;<br>1: enable interrupt request on measured accel. value higher than preset threshold) |
| YS | Enable interrupt single click on Y-axis. Default value: 0<br>(0: disable interrupt request;<br>1: enable interrupt request on measured accel. value higher than preset threshold) |
| XD | Enable interrupt double click on X-axis. Default value: 0<br>(0: disable interrupt request;<br>1: enable interrupt request on measured accel. value higher than preset threshold) |
| XS | Enable interrupt single click on X-axis. Default value: 0<br>(0: disable interrupt request;<br>1: enable interrupt request on measured accel. value higher than preset threshold) |

### 8.30 CLICK\_SRC (39h)

#### Table 73. CLICK\_SRC register

|  | IA | DCLICK | SCLICK | Sign | Z | Y | X |
|--|----|---|---|---|---|---|---|
|--|----|--------|--------|------|---|---|---|

#### Table 74. CLICK\_SRC description

| IA | Interrupt active. Default value: 0<br>(0: no interrupt has been generated; 1: one or more interrupts have been generated) |
|---|---|
| DCLICK | Double-click enable. Default value: 0<br>(0: double-click detection disabled, 1: double-click detection enabled) |
| SCLICK | Single-click enable. Default value: 0<br>(0: Single-click detection disabled, 1: single-click detection enabled) |
| Sign | Click sign.<br>(0: positive detection, 1: negative detection) |
| Z | Z click detection. Default value: 0<br>(0: no interrupt, 1: Z high event has occurred) |
| Y | Y click detection. Default value: 0<br>(0: no interrupt, 1: Y high event has occurred) |
| X | X click detection. Default value: 0<br>(0: no interrupt, 1: X high event has occurred) |

### 8.31 CLICK\_THS (3Ah)

#### Table 75. CLICK\_THS register

| LIR_Click | Ths6 | Ths5 | Ths4 | Ths3 | Ths2 | Ths1 | Ths0 |
|---|---|---|---|---|---|---|---|
|-----------|------|------|------|------|------|------|------|

#### Table 76. CLICK\_SRC description

| LIR_Click | If the LIR_Click bit is not set, the interrupt is kept high for the duration of the latency window.<br><br>If the LIR_Click bit is set, the interrupt is kept high until the <i>CLICK_SRC (39h)</i> register is read. |
|---|---|
| Ths[6:0]  | Click threshold. Default value: 000 0000 |

### 8.32 TIME\_LIMIT (3Bh)

#### Table 77. TIME LIMIT register

| - | TLI6 | TLI5 | TLI4 | TLI3 | TLI2 | TLI1 | TLI0 |
|---|---|---|---|---|---|---|---|
|---|------|------|------|------|------|------|------|

#### Table 78. TIME\_LIMIT description

| TLI[6:0] | Click time limit. Default value: 000 0000 |
|---|---|
|----------|-------------------------------------------|

577

Registers description LIS3DH

### 8.33 TIME\_LATENCY (3Ch)

#### Table 79. TIME\_LATENCY register

| TLA7 | TLA6 | TLA5 | TLA4 | TLA3 | TLA2 | TLA1 | TLA0 |
|---|---|---|---|---|---|---|---|
|------|------|------|------|------|------|------|------|

#### Table 80. TIME\_LATENCY description

| TLA[7:0] | Click time latency. Default value: 0000 0000 |
|---|---|
|----------|----------------------------------------------|

### 8.34 TIME WINDOW (3Dh)

#### Table 81. TIME\_WINDOW register

| TW7 | TW6 | TW5 | TW4 | TW3 | TW2 | TW1 | TW0 |
|-----|-----|-----|-----|-----|-----|-----|-----|
|-----|-----|-----|-----|-----|-----|-----|-----|

#### Table 82. TIME\_WINDOW description

| TWI[7:0] | Click time window |
|---|---|
|----------|-------------------|

### 8.35 ACT\_THS (3Eh)

#### Table 83. ACT\_THS register

| -- | Acth6 | Acth5 | Acth4 | Acth3 | Acth2 | Acth1 | Acth0 |
|----|---|---|---|---|---|---|---|
|----|-------|-------|-------|-------|-------|-------|-------|

#### Table 84. ACT\_THS description

| Acth[6:0] | Sleep-to-wake, return-to-sleep activation threshold in low-power mode<br>1 LSb = 16 mg @ FS = $±2$ g<br>1 LSb = 32 mg @ FS = $±4$ g<br>1 LSb = 62 mg @ FS = $±8$ g<br>1 LSb = 186 mg @ FS = $±16$ g |
|---|---|
|-----------|-----------------------------------------------------------------------------------------------------------------------------------------------------------------------------------------------------|

### 8.36 ACT\_DUR (3Fh)

#### Table 85. ACT\_DUR register

| ActD7 | ActD6 | ActD5 | ActD4 | ActD3 | ActD2 | ActD1 | ActD0 |
|---|---|---|---|---|---|---|---|
|-------|-------|-------|-------|-------|-------|-------|-------|

#### Table 86. ACT\_DUR description

| ActD[7:0] | Sleep-to-wake, return-to-sleep duration |
|---|---|
| | 1 LSb = $(8*1[LSb]+1)/ODR$ |

LIS3DH Package information

## 9 Package information

In order to meet environmental requirements, ST offers these devices in different grades of ECOPACK<sup>®</sup> packages, depending on their level of environmental compliance. ECOPACK<sup>®</sup> specifications, grade definitions and product status are available at: www.st.com. ECOPACK is an ST trademark.



**Package information** LIS3DH

#### 9.1 **LGA-16** package information

Figure 12. LGA-16 package outline and mechanical dimensions



7983231\_13

LIS3DH Package information

### 9.2 LGA-16 packing information

Figure 13. Carrier tape information for LGA-16 package



Figure 14. LGA-16 package orientation in carrier tape



Package information LIS3DH



Figure 15. Reel information for carrier tape of LGA-16 package

Table 87. Reel dimensions for carrier tape of LGA-16 package

| Reel dimensions (mm) | |
|---|---|
| A (max) | 330 |
| B (min) | 1.5 |
| C | 13 ±0.25 |
| D (min) | 20.2 |
| N (min) | 60 |
| G | 12.4 +2/-0 |
| T (max) | 18.4 |

LIS3DH Revision history

## 10 Revision history

Table 88. Document revision history

| Date | Revision | Changes |
|---|---|---|
| 21-May-2010 | 1 | Initial release |
| 12-Dec-2016 | 2 | Updated Table 1: Device summary Updated Features and Figure 1: Block diagram Updated Table 2: Pin description and Table 14: Serial interface pin description Added Table 3: Internal pull-up values (typ.) for SDO/SAO pin Updated Table 9: Absolute maximum ratings Updated Section 3.7: Auxiliary ADC and temperature sensor Updated Section 4: Application hints Updated Section 5: Digital main blocks Updated Section 7: Register mapping and Section 8: Registers description Updated Section 9.1: LGA-16 package information Added Section 9.2: LGA-16 packing information Minor textual updates |

#### IMPORTANT NOTICE - PLEASE READ CAREFULLY

STMicroelectronics NV and its subsidiaries ("ST") reserve the right to make changes, corrections, enhancements, modifications, and improvements to ST products and/or to this document at any time without notice. Purchasers should obtain the latest relevant information on ST products before placing orders. ST products are sold pursuant to ST's terms and conditions of sale in place at the time of order acknowledgement.

Purchasers are solely responsible for the choice, selection, and use of ST products and ST assumes no liability for application assistance or the design of Purchasers' products.

No license, express or implied, to any intellectual property right is granted by ST herein.

Resale of ST products with provisions different from the information set forth herein shall void any warranty granted by ST for such product.

ST and the ST logo are trademarks of ST. All other product or service names are the property of their respective owners.

Information in this document supersedes and replaces information previously supplied in any prior versions of this document.

© 2016 STMicroelectronics – All rights reserved

477

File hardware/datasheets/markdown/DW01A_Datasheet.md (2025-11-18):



### **General Description**

The DW01A battery protection IC is designed to protect lithium-ion/polymer battery from damage or degrading the lifetime due to overcharge, overdischarge, and/or overcurrent for one-cell lithium-ion/polymer battery powered systems, such as cellular phones.

The ultra-small package and less required external components make it ideal to integrate the DW01A into the limited space of battery pack. The accurate ±50mV overcharging detection voltage ensures safe and full utilization charging. The very low standby current drains little current from the cell while in storage.

### **Ordering Information**

DW01A

PACKAGE TYPE SOT-23-6

TEMPERATURE RANGE -40°C~+85°C

OVERCHARGE PROTECTION 4.3V± 50mV

#### **Features**

- Reduction in Board Size due to Miniature Package SOT-23-6.
- Ultra-Low Quiescent Current at 3 μ A (Vcc=3.6V).
- Overdischarge Current at 4  $\mu$ A (Vcc=1.8V).
- Precision Overcharge Protection Voltage 4.3V ± 50mV
- Two Detection Levels for Overcurrent Protection.
- Delay times are generated by internal circuits.
  No external capacitors required.

#### **Applications**

 Protection IC for One-Cell Lithium-Ion / Lithium-Polymer Battery Pack



### **Product Name List**

| Product | Package  | dotoction | Overcharge<br>release<br>voltage<br>[VOCR] (V) | Overdischarge<br>detection<br>voltage<br>[VODP] (V) | Overdischarge<br>release<br>voltage<br>[VODR] (V) | Overcurrent<br>detection<br>voltage<br>[VoI1] (mV) | 0V<br>battery<br>charge<br>function | Stand by<br>function<br>release |
|---|---|---|---|---|---|---|---|---|
| DW01A | SOT-23-6 | 4.300±0.050 | 4.100±0.050 | 2.50±0.1 | 2.90±0.1 | 150±20 | available | Auto<br>Recovery |

# **Pin Configuration**

| Pin No. | Symbol | Description |  |  |
|---|---|---|--|--|
| 1 | OD | MOSFET gate connection pin for discharge control |  |  |
| 2 | VM | Input pin for current sense, charger detect |  |  |
| 3 | ОС | MOSFET gate connection pin for charge control |  |  |
| 4 | TD | Test pin for reduce delay time |  |  |
| 5 | VCC | Power supply, through a resistor (R1) |  |  |
| 6 | GND | Ground pin |  |  |





# **Functional Block Diagram**





# **Typical Application Circuit**


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

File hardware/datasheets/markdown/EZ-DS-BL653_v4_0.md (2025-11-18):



# **Datasheet**

**BL653** 

Version 4.0



# **Revision History**

| | / | | | |
|---|---|---|---|---|
| Version | Date | Notes | Contributor(s) | Approver |
| 1.0 | 04 Jun 2020  | Initial version | Raj Khatri | Jonathan Kaye  |
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

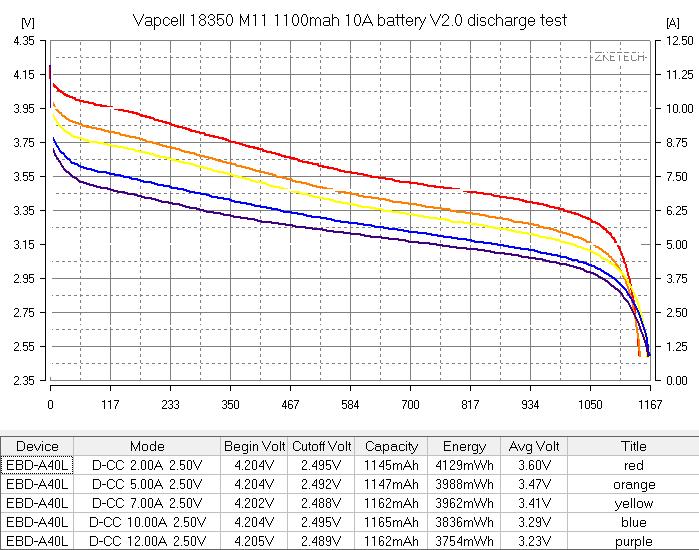
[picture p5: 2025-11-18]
hardware/datasheets/pdf/Vapcell_18350_discharge_curve.jpg

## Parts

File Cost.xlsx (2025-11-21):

Part | Cost [€] | Column1 | Notes
Per pcs costs
PCB @ 10 pcs | 0.434
Economic PCBA Assembly @ 10 pcs | 2.662
Parts Excluded from BOM (excl. TAX)
USB4105-GF-A-060 | 0.569
USBLC6-2SC6 | 0.21
453-00039R | 3.71 |  | Price for Only 5 pcs
Vapcell 18350 | 5.27
PAM2804AAB010 | 0.297
XPEBRD-L1-0000-00801 | 1.493
LIS3DHTR | 1.086
OPT3001DNPR | 1.676
One-time costs
PCB Shipping | 8.68
Tariffs (JLCPCB) | 7.93
TAX (Digikey) | 28.622
Cost per piece | 21.9302
Pieces | 10
Total Cost | 219.302

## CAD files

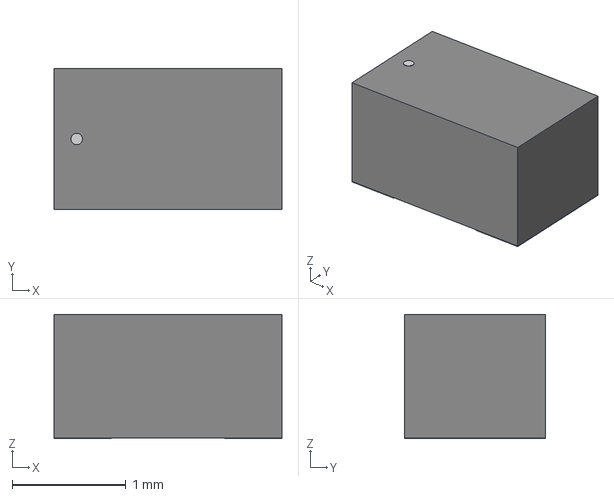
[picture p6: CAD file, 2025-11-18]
hardware/kicad_3d_models/LED_LTST-C170KSKT_LTO.step
2.01 x 1.24 x 1.09 mm

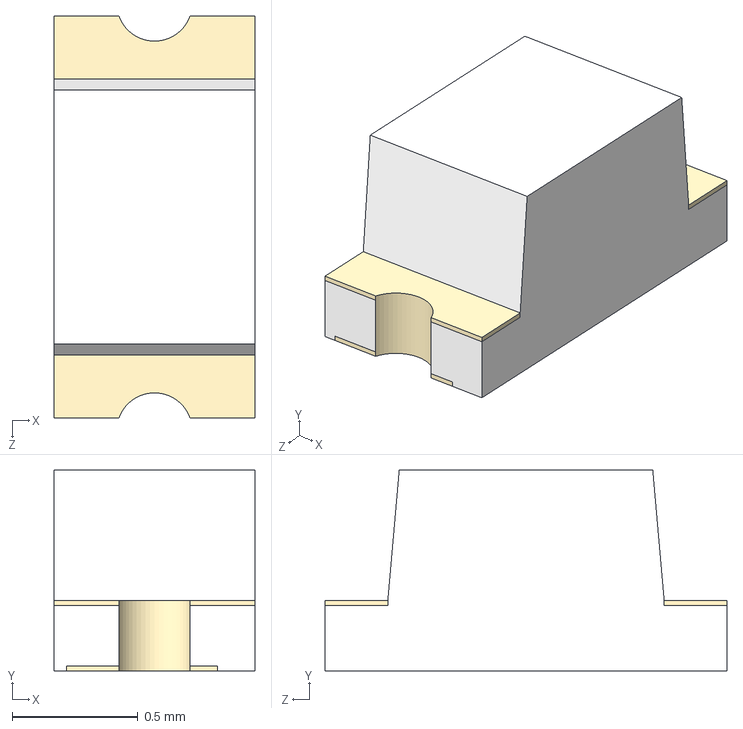
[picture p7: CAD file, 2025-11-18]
hardware/kicad_3d_models/LTST-C190KRKT.step
0.8 x 0.8 x 1.60 mm

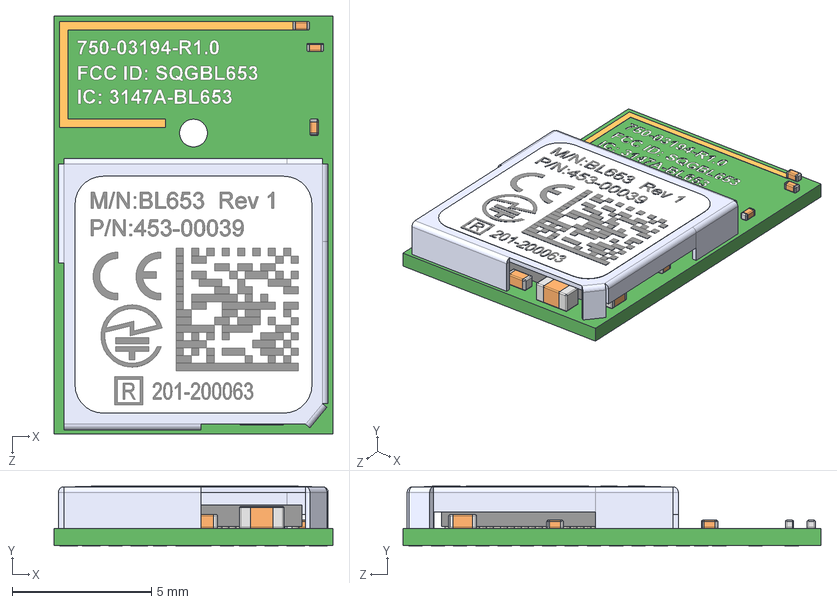
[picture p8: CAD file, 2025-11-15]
hardware/kicad_3d_models/BL653 453-00039_3D Model with label.STEP
10.0 x 2.14 x 15.0 mm

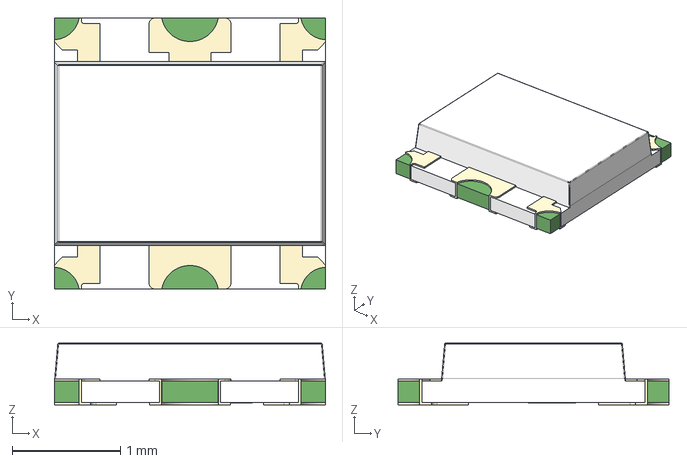
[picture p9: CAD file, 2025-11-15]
hardware/kicad_3d_models/LTRB_RASF.01-6B6C-C3E6-0-0-R18.stp
2.50 x 2.50 x 0.57 mm

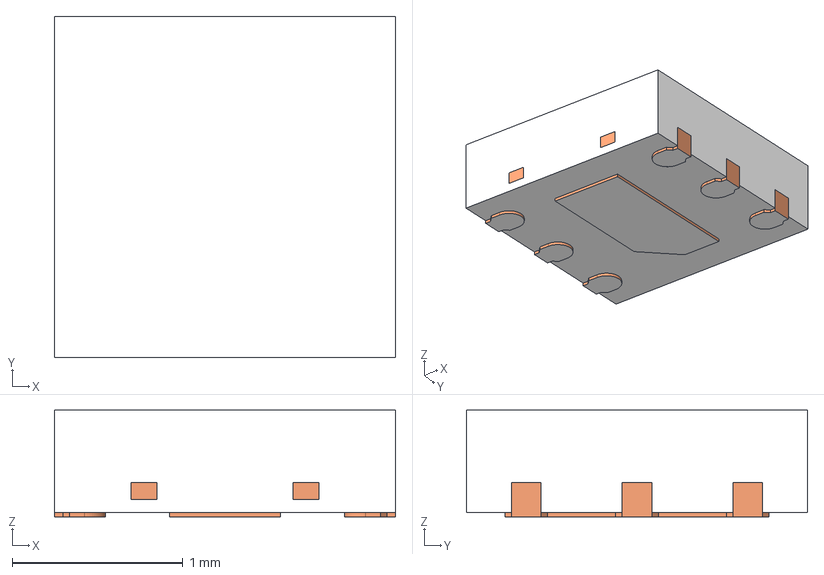
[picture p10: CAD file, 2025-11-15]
hardware/kicad_3d_models/OPT3001DNPR.stp
2.00 x 2.00 x 0.625 mm
BODY-SON
FRAME-DNP0006A
PIN1-ID
DIE
BOND_WIRE_AF0
BOND_WIRE_AF1
BOND_WIRE_AF2
BOND_WIRE_AF3
BOND_WIRE_AF4
BOND_WIRE_AF5

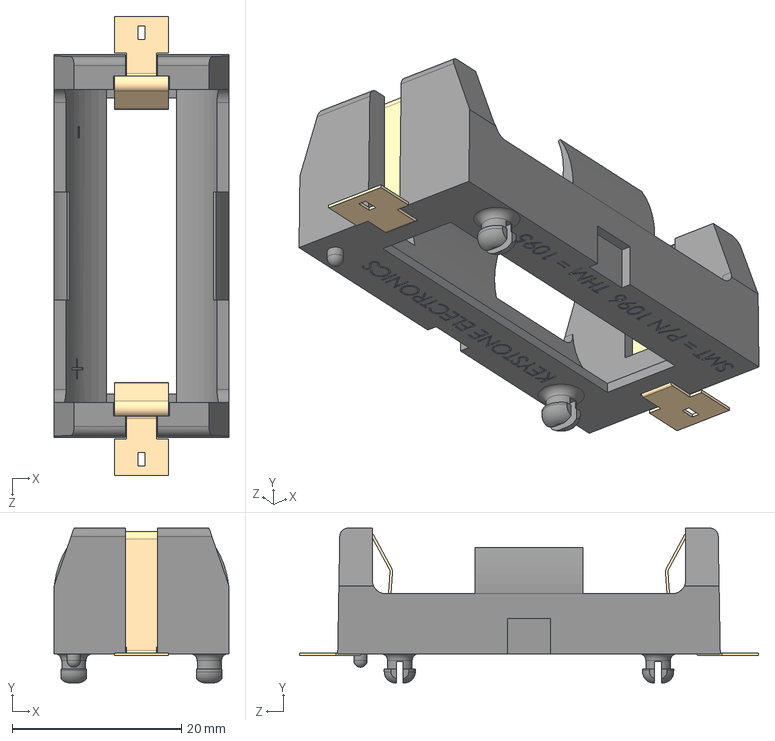
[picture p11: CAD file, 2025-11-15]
hardware/kicad_3d_models/1096.step
20.7 x 18.3 x 54.2 mm

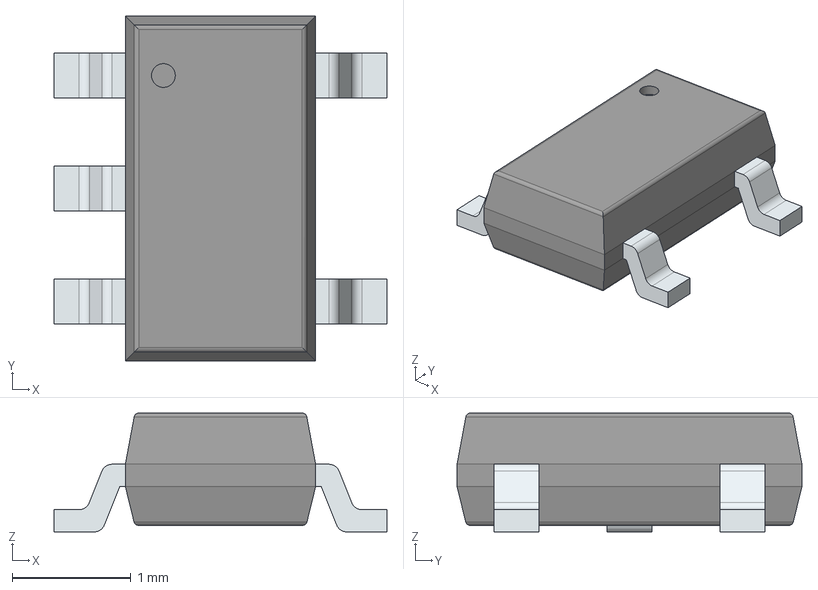
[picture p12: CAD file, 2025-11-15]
hardware/kicad_3d_models/PAM2804AAB010.stp
2.80 x 2.90 x 1.00 mm
PinsArrayL
PinsArrayR

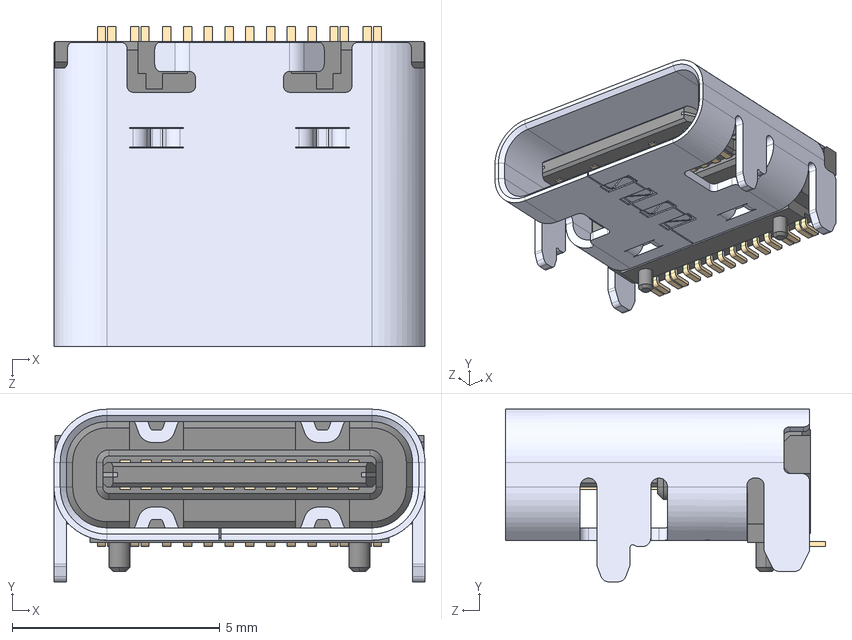
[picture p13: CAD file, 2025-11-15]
hardware/kicad_3d_models/USB4105GFA060.step
8.94 x 4.16 x 7.71 mm

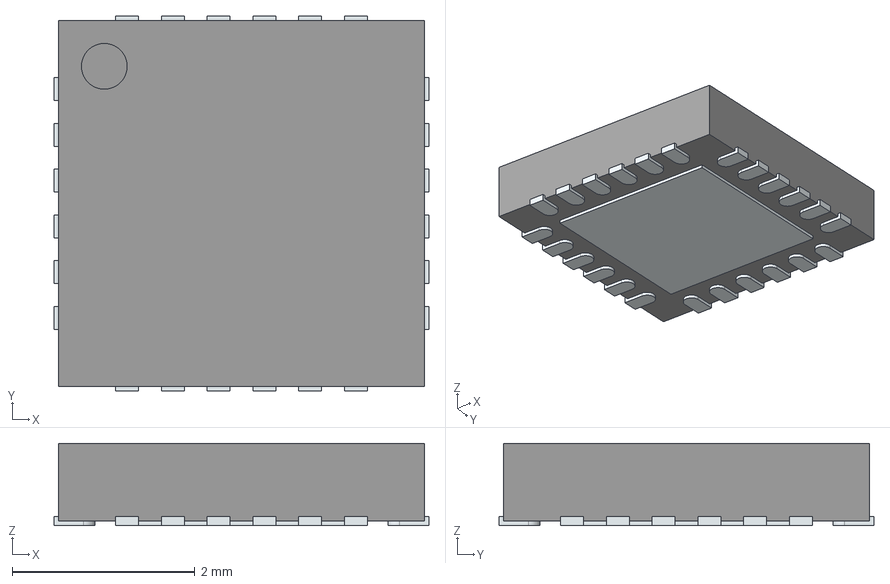
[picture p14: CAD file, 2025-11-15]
hardware/kicad_3d_models/NPM1100-QDAA-R.stp
4.10 x 4.10 x 0.9 mm
ThermalPin
PinsArrayLR
PinsArrayTB

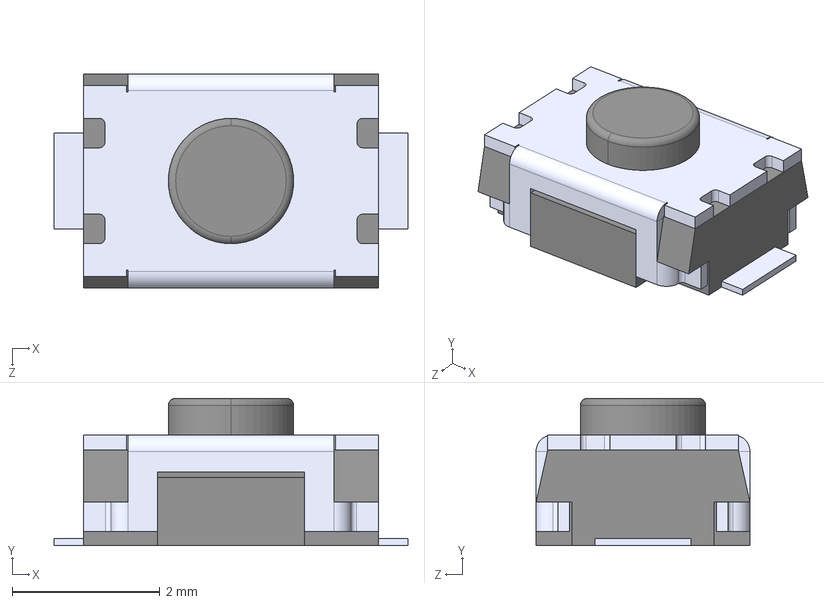
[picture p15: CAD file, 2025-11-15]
hardware/kicad_3d_models/TS-1088-AR02016.step
4.80 x 2.00 x 2.90 mm

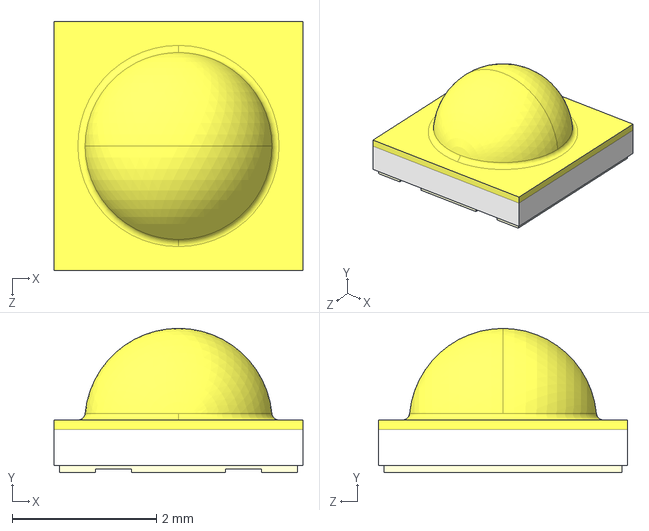
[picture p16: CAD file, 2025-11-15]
hardware/kicad_3d_models/XPEBFR-L1-0000-00901.stp
3.45 x 2.00 x 3.45 mm

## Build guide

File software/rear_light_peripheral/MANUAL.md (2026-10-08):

# Bike Light Rear - User Manual

## Overview

The bike light rear is a high-visibility intelligent bicycle tail light featuring three light modes (Steady, Flash, Smart), smart braking detection, ambient light sensing, and automatic power-saving functionality.

## Operating Modes

The light steps through its modes via short button press:

```
Deep Sleep → Smart → Steady → Flash → Deep Sleep
```

The three light modes (Smart, Steady, Flash) are the **Active Modes**. After the last one, a short press enters Deep Sleep, or Idle Charging when USB power is present (see below).

### Deep Sleep
- **Description**: Light is completely off; the device is in deep sleep (System OFF)
- **Power Consumption**: Minimal (only the button wake circuit is active)
- **Wake**: Press the button to wake; the light starts in Smart
- **Bluetooth**: Not reachable while in Deep Sleep

### Steady
- **Description**: Steady illumination at base brightness
- **PWM Frequency**: 1 kHz
- **Duty Cycle**: 20% (200µs pulse width)
- **Use Case**: General visibility in moderate traffic
- **Activation**: Press button from Smart

### Flash (High Visibility)
- **Description**: Enhanced visibility mode with a periodic double flash
- **Base Brightness**: 200µs pulse width (20% duty), continuous
- **Flash Pattern**: Double flash every 1.5 seconds - peak (800µs, 80% duty) for 70ms, base for 70ms, peak for 70ms, then back to base. The first double flash comes 1.5 seconds after entering the mode.
- **PWM Frequency**: 1 kHz
- **Use Case**: High-traffic environments, increased attention-grabbing
- **Activation**: Press button from Steady

### Smart (Adaptive)
- **Description**: Intelligent adaptive lighting based on environmental conditions and rider behavior
- **Features**:
  - Automatic braking detection
  - Ambient light sensing
  - Automatic power-off when stationary
- **Activation**: Press button from Deep Sleep (wake), Idle Charging or Off
- **See detailed behavior below**

### Off (Bluetooth only)

The light can also be put into **Off** over Bluetooth: the light is dark but the device stays awake and connectable. Off is never entered with the button. A short press in Off starts the first light mode (Smart). Off has no timeout.

### Button behavior summary

- **Short press** (released within 1 second):
  - Steps through the light modes: `Smart → Steady → Flash`
  - After the last light mode (Flash), the light enters **Deep Sleep**, or **Idle Charging** when USB power is present. A short press in Idle Charging (or in Off) starts the first light mode again (Smart).
  - **Selection window (about 15 to 20 seconds):** you can step through the light modes only for a short time after the light was switched on (from Deep Sleep, Off or Idle Charging, also after a restart). After that, a short press in any light mode switches the light off (Deep Sleep, or Idle Charging when USB power is present) instead of going to the next mode. For example, in Steady after the window, a press goes to Deep Sleep, not to Flash. Nothing signals the end of the window. To change the mode later, switch the light off and on again. The length varies by up to 5 seconds because the window is counted in battery sampling ticks.- **Long press** (held for 1 second or longer):
  - Turns the light **off immediately from any mode** (including with USB power present) and enters Deep Sleep. It acts at the 1 second mark; you do not have to release first.
- **Wake from sleep**:
  - After the light has turned itself fully off and entered Deep Sleep, a press wakes it and starts in Smart. The wake press does nothing else; keep holding it and nothing more happens, and the next press counts as a new press.

## Smart Mode Detailed Behavior

Smart adapts LED brightness based on three environmental factors.
Brightness priority: **Braking (Peak, 800µs) > Darkness (Base, 200µs) > Off**.

When Smart starts, the LED is off until the first dark detection (about one second in the dark).

### 1. Braking Detection

**Detection Criteria:**
- The Z-axis acceleration (positive = decelerating, negative = accelerating, sensor mounted with Z along the direction of travel) is corrected for gravity with a slow baseline (time constant 8 s) and averaged over 150 ms
- Braking starts when this value stays above **+5.0 m/s²** for **100 ms** (2 samples at 50 ms)

**Behavior When Braking:**
- LED immediately switches to **Peak brightness** (800µs PWM)
- Overrides ambient light settings
- The baseline stops adapting while braking, so a long brake does not cancel itself out

**Braking End Detection:**
- The value stays at or below +5.0 m/s² for **150 ms**, and the light keeps shining for **1 more second** (`BRAKING_HOLD_MS`) after the braking phase has ended. Braking again during that second keeps the light on without a gap
- LED returns to the brightness dictated by ambient light

### 2. Ambient Light Control

- **Darkness threshold**: < 50 lux for 2 consecutive samples → LED at base brightness
- **Brightness threshold**: ≥ 150 lux for 2 consecutive samples → LED off (hysteresis prevents flicker from the light's own output)

### 3. Automatic Power-Off

**Stationary Detection:**
- Monitors acceleration magnitude: √(x² + y² + z²)
- Expected value when stationary: ~9.81 m/s² (Earth's gravity)
- Tolerance: ±100% (0 - 19.62 m/s²)

**Auto-Off Criteria:**
- **2.5 minutes** (150 s) of uninterrupted samples within the stationary range
- Any sample outside the range (road vibration, movement) resets the counter
- Only active in Smart

**When Auto-Off Triggers:**
- Light switches off and enters Deep Sleep to save battery, also when USB power is present.
- Requires a manual button press to wake and reactivate (starts in Steady).

### Sensor failure

If a sensor does not start, Smart keeps working with the other one. Without the light sensor the LED stays off. Without the accelerometer there is no braking boost and no auto-off.

## Charging & Battery Behavior

### Normal charging

- **USB-C port** on the light is used for charging the 18350 cell. Charging is done by autonomous hardware, also while the light is in Deep Sleep.
- Powering up (or plugging in USB while in Deep Sleep) with **USB power** boots the light into **Idle Charging** (main LED off).
- **Plugging in USB while the light is on never changes the mode**, so the light stays on, for example if a power bank is connected mid-ride. Only the status LED changes.
- While USB power is present, the **status LED blinks fast (300ms)** to show charging activity, in every awake state.
- **Unplugging USB** while in Idle Charging powers the light off (Deep Sleep); press the button to turn it back on.

### Low-battery indication and shut-off

- Battery voltage is sampled every 5 seconds in all modes.
- **Low battery** (below ~3.4V for 3 consecutive samples): the status LED blinks slowly (500ms) to signal that a recharge is due. Recovers automatically when the voltage stays at or above 3.4V. **The status LED is the only low-battery warning**: it is meant to be seen by the rider, and the main light is not changed in any way until the battery is critical.
- **Critical battery** (below ~3.0V for 3 consecutive samples): the light turns off and enters Deep Sleep to protect the cell.
- To use the light again, **recharge the battery** and press the button to wake it. Waking with a critical battery turns the light on briefly until the critical shut-off triggers again.
- Battery readings are not reliable while USB power is present.

### Status LED priority

1. Low battery → 500ms blink
2. Charging (USB power present) → 300ms blink
3. Light in an active mode → solid on
4. Otherwise → off

## Technical Specifications

### Sensor System

**Accelerometer (LIS3DH):**
- 3-axis motion detection
- Polling interval: 50ms (20 Hz), only while in Smart
- Output data rate: 25 Hz
- Range: ±2g typical
- Interface: I²C

**Light Sensor (OPT3001):**
- Range: 0.01 - 83,000 lux
- Human-eye spectral matching
- Sampling Rate: 500ms (2 Hz), only while in Smart
- Interface: I²C

### LED Driver

**LED Specifications:**
- Type: Cree XP-E2 Red (625nm)
- Drive Current: 500mA
- Driver: PAM2804 constant-current step-down

**PWM Control:**
- Frequency: 1 kHz (1000µs period)
- Resolution: 1µs
- Brightness Levels:
  - Off: 0µs pulse width
  - Base: 200µs pulse width (20% duty)
  - Peak (braking/flash): 800µs pulse width (80% duty)

### Power Management

**Battery:**
- Type: Single 18350 Li-ion cell
- Capacity: 1100mAh (Vapcell)
- Operating Range: 3.11V - 4.2V

**System Voltage:**
- Regulated: 2.7V (NPM1100 buck regulator)
- Efficiency: 90-95% battery utilization

**Protection:**
- Over-voltage: 4.3V cutoff
- Under-voltage: 2.5V cutoff (DW01A protection IC)
- Over-current: >2A protection

**Battery Measurement:**
- SAADC on AIN5 through a 1M/100k divider, sampled every 5 seconds

## State Transition Diagram

```mermaid
stateDiagram-v2
    [*] --> Deep_Sleep
    Deep_Sleep --> Smart: Button Press (wake)
    Smart --> Steady: Short Press
    Steady --> Flash: Short Press
    Flash --> Deep_Sleep: Short Press (no USB)
    Flash --> Idle_Charging: Short Press (USB present)
    Smart --> Deep_Sleep: Auto-Off
    Idle_Charging --> Smart: Short Press
    Idle_Charging --> Deep_Sleep: USB unplugged
    Steady --> Deep_Sleep: Long Press
    Flash --> Deep_Sleep: Long Press
    Smart --> Deep_Sleep: Long Press
    Idle_Charging --> Deep_Sleep: Long Press
    Deep_Sleep --> Idle_Charging: USB plugged in (reset)

    state Smart {
        [*] --> Bright_Daylight
        Bright_Daylight --> Dark: Light < 50 lux (2 samples)
        Dark --> Bright_Daylight: Light >= 150 lux (2 samples)

        state Bright_Daylight {
            [*] --> LED_Off
            LED_Off --> Braking_Peak: Braking Detected
            Braking_Peak --> LED_Off: Braking Ended
        }

        state Dark {
            [*] --> LED_Base
            LED_Base --> Braking_Peak: Braking Detected
            Braking_Peak --> LED_Base: Braking Ended
        }
    }
```

"Smart → Steady → Flash" is the configured mode order. The mode arrows apply only within the selection window of about 15 to 20 seconds after switching on; after it, a short press in any light mode goes to Deep Sleep (or Idle Charging with USB power present). A different order changes the arrows between the light modes, but Idle Charging (or Deep Sleep) always follows the last one. Off (Bluetooth only) is not shown.

## Usage Recommendations

### Daytime Riding
- Use **Flash** mode for maximum visibility in bright conditions
- Or use **Smart** which will activate only during braking

### Night Riding
- Use **Steady** for steady visibility
- Or use **Smart** which provides the base brightness with braking boost

### Commuting
- **Smart** is ideal for mixed urban/traffic conditions
- Automatic brightness adjustment reduces manual intervention
- Auto-off prevents battery drain if bike is left stationary

## Optional Bluetooth Control (for advanced users)

The rear light includes a simple Bluetooth Low Energy (BLE) interface. It is available whenever the device is awake (not in Deep Sleep), supports one connection at a time, and is **not authenticated**: any device in range can change the mode.

- Service UUID `0xA000` (advertised)
- Characteristic `0xA001` (read): current state as one byte (0=Off, 1=Steady, 2=Flash, 3=Smart, 4=Idle Charging)
- Characteristic `0xA002` (write): requested state as one byte. Valid requests are 0 (Off), 1 (Steady), 2 (Flash), 3 (Smart). Idle Charging (4) cannot be requested; it is set only by USB power. Invalid requests are ignored.
- A write always reports success, even when the request is ignored. Read `0xA001` to see the result.
- Remote mode changes are ignored for 3 seconds after any local mode change (and after boot), so a connected device cannot fight a just-pressed button.
- A BLE-written Off keeps the device awake and connectable; only the button and the safety features enter Deep Sleep.
- Button presses and safety features (braking, auto-off, low battery) always take priority over BLE control.

For developers or integrators who want to use BLE control, see `src/ble.c` in the firmware source.

## Firmware Information

**Build System:** nRF Connect SDK v3.1.1
**Target Device:** Nordic nRF52833 (BL653 module)
**RTOS:** Zephyr OS
**Programming Interface:** SWD (Serial Wire Debug)

**Software Architecture:**
- Event-driven central state machine: every input (button, BLE write, battery tick, USB plug/unplug, sensor detections) is posted as an event into one message queue
- Main thread runs the state machine event loop and is the only writer of system state and light output
- Sensor thread: accelerometer (50ms) and light sensor (500ms) sampled on independent schedules in Smart, posts edge events (brake start/stop, dark/bright, stationary timeout). Detection times are defined in milliseconds, independent of the sampling intervals
- Timer ISRs and BLE callbacks only post events - no state is modified outside the state machine thread
- If the main LED, status LED or button fails to initialize at boot, the firmware resets instead of stopping
- There is no watchdog

**Key Configuration Options:**
- `MODE_SELECT_WINDOW_BATTERY_TICKS`: 4 battery ticks (5 s each) = 15 to 20 s (in `src/state_machine.c`)
- `BRAKING_ACCEL_THRESHOLD_MILLI`: +5000 milli-m/s² (in `src/sensors.c`)
- `BRAKING_START_CONFIRM_MS` / `BRAKING_STOP_CONFIRM_MS` / `BRAKING_HOLD_MS` / `BRAKING_SMOOTHING_MS` / `BRAKING_BASELINE_TAU_MS`: 100 / 150 / 1000 / 150 / 8000 ms (in `src/sensors.c`)
- `ACCEL_SAMPLING_INTERVAL_MS` / `LIGHT_SAMPLING_INTERVAL_MS` / `ACCEL_ODR_HZ`: 50 / 500 ms / 25 Hz (in `src/sensors.c`)
- `AMBIENT_DARK_THRESHOLD_MILLILUX` / `AMBIENT_BRIGHT_THRESHOLD_MILLILUX`: 50 / 150 lux (in `src/sensors.c`)
- `STATIONARY_TIMEOUT_MS`: 150000 ms = 2.5 minutes (in `src/sensors.c`)
- `BATTERY_CRITICAL_MV` / `BATTERY_LOW_MV`: 3000 / 3400 mV (in `src/battery.c`)
- `LIGHT_PULSE_BASE` / `LIGHT_PULSE_PEAK`: 200 / 800 µs (in `inc/light.h`)

See `SPEC.md` for the full behavioural specification and `CONTEXT.md` for the terminology.

## License

Copyright © 2025 Matthias Dippold

This firmware is released under **GPLv3 + NonCommercial**.
See LICENSE file for complete terms.

---

**Firmware Version:** 2.0.0 (Event-Driven State Machine Rebuild)
**Last Updated:** October 2026
**For support and updates:** See main README.md

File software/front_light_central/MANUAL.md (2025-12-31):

# Bike Light Rear - User Manual

## Overview

The bike light rear is a high-visibility intelligent bicycle tail light featuring four operating modes, smart braking detection, ambient light sensing, and automatic power-saving functionality.

## Operating Modes

The light cycles through four modes via button press, returning to OFF after the last mode:

```
OFF → 50% → 50/80 Flash → Smart Mode → OFF
```

### Mode 1: OFF
- **Description**: Light is completely off
- **Power Consumption**: Minimal (sensor monitoring continues)
- **Activation**: Press button from Smart Mode

### Mode 2: 50% Continuous
- **Description**: Steady illumination at 50% brightness
- **PWM Frequency**: 1 kHz
- **Duty Cycle**: 50% (500µs pulse width)
- **Use Case**: General visibility in moderate traffic
- **Activation**: Press button from OFF mode

### Mode 3: 50/80 Flash (High Visibility)
- **Description**: Enhanced visibility mode with periodic brightness flashes
- **Base Brightness**: 50% continuous
- **Flash Pattern**: 80% brightness flash for 100ms every 1.5 seconds
- **PWM Frequency**: 1 kHz
- **Use Case**: High-traffic environments, increased attention-grabbing
- **Activation**: Press button from 50% mode

### Mode 4: Smart Mode (Adaptive)
- **Description**: Intelligent adaptive lighting based on environmental conditions and rider behavior
- **Features**:
  - Automatic braking detection
  - Ambient light sensing
  - Automatic power-off when stationary
- **Activation**: Press button from 50/80 Flash mode
- **See detailed behavior below**

## Smart Mode Detailed Behavior

Smart Mode adapts LED brightness based on three environmental factors:

### 1. Braking Detection

**Detection Criteria:**
- Z-axis acceleration < -3.0 m/s² for **2 consecutive samples** (1 second total)
- Rear-facing sensor orientation: negative Z indicates deceleration

**Behavior When Braking:**
- LED immediately switches to **80% brightness** (800µs PWM)
- Overrides ambient light settings
- Previous brightness state is saved

**Braking End Detection:**
- Z-axis acceleration returns above -3.0 m/s² for **2 consecutive samples**
- LED returns to previous brightness state (based on ambient light)

### 2. Ambient Light Control

**Darkness Threshold:** < 50 lux

### 3. Automatic Power-Off

**Stationary Detection:**
- Monitors acceleration magnitude: √(x² + y² + z²)
- Expected value when stationary: ~9.81 m/s² (Earth's gravity)
- Tolerance: ±10% (8.829 - 10.791 m/s²)

**Auto-Off Criteria:**
- ALL of the last **300 samples** (2.5 minutes) must be within stationary range
- Check performed every 60 seconds (energy efficient)
- Only activates if currently in Smart Mode

**When Auto-Off Triggers:**
- Light switches to OFF mode
- Requires manual button press to reactivate

## Technical Specifications

### Sensor System

**Accelerometer (LIS3DH):**
- 3-axis motion detection
- Sampling Rate: 500ms (2 Hz)
- Range: ±2g typical
- Interface: I²C

**Light Sensor (OPT3001):**
- Range: 0.01 - 83,000 lux
- Human-eye spectral matching
- Sampling Rate: 500ms (2 Hz)
- Interface: I²C

**Temperature Sensor:**
- Internal nRF52833 die temperature
- Used for system monitoring

### Data Buffer

**Circular Buffer:**
- Size: 360 samples
- Duration: 3 minutes of history
- Sampling Period: 500ms
- Thread Safety: Zephyr read-write lock (`sys_rwlock`)
- Stored Data: Temperature, ambient light, acceleration (X, Y, Z)

**Buffer Management:**
- Continuous overwrite (oldest data replaced)
- Thread-safe concurrent access
- Separate reader/writer threads

### LED Driver

**LED Specifications:**
- Type: Cree XP-E2 Red (625nm)
- Drive Current: 500mA
- Driver: PAM2804 constant-current step-down

**PWM Control:**
- Frequency: 1 kHz (1000µs period)
- Resolution: 1µs
- Brightness Levels:
  - 0%: 0µs pulse width (OFF)
  - 50%: 500µs pulse width
  - 80%: 800µs pulse width

### Power Management

**Battery:**
- Type: Single 18350 Li-ion cell
- Capacity: 1100mAh (Vapcell)
- Operating Range: 3.11V - 4.2V

**System Voltage:**
- Regulated: 2.7V (NPM1100 buck regulator)
- Efficiency: 90-95% battery utilization

**Protection:**
- Over-voltage: 4.3V cutoff
- Under-voltage: 2.5V cutoff (DW01A protection IC)
- Over-current: >2A protection

## State Transition Diagram

```mermaid
stateDiagram-v2
    [*] --> OFF
    OFF --> 50_Percent: Button Press
    50_Percent --> Flash_50_80: Button Press
    Flash_50_80 --> Smart_Mode: Button Press
    Smart_Mode --> OFF: Button Press OR Auto-Off
    OFF --> [*]
    
    state Smart_Mode {
        [*] --> Bright_Daylight
        Bright_Daylight --> Dark: Light < 30 lux
        Dark --> Bright_Daylight: Light >= 30 lux
        
        state Bright_Daylight {
            [*] --> LED_Off
            LED_Off --> Braking_80: Braking Detected
            Braking_80 --> LED_Off: Braking Ended
        }
        
        state Dark {
            [*] --> LED_50
            LED_50 --> Braking_80: Braking Detected
            Braking_80 --> LED_50: Braking Ended
        }
    }
```

## Usage Recommendations

### Daytime Riding
- Use **50/80 Flash** mode for maximum visibility in bright conditions
- Or use **Smart Mode** which will activate only during braking

### Night Riding
- Use **50% Continuous** for steady visibility
- Or use **Smart Mode** which provides 50% baseline with braking boost

### Commuting
- **Smart Mode** is ideal for mixed urban/traffic conditions
- Automatic brightness adjustment reduces manual intervention
- Auto-off prevents battery drain if bike is left stationary

### Long-Term Storage
- Switch to **OFF mode** to minimize power consumption
- Charge battery to ~50% for optimal storage
- Disconnect battery if storing for extended periods (>3 months)

## Troubleshooting

### Light doesn't turn on
- Check battery charge level
- Verify battery protection circuit hasn't tripped (cycle charge)
- Ensure firmware is loaded correctly

### Smart Mode not responding to braking
- Verify accelerometer orientation (Z-axis must face rear)
- Check sensor I²C connection (use DEBUG mode)
- Confirm sampling period is 500ms

### Premature auto-off in Smart Mode
- May indicate excessive vibration/noise in accelerometer
- Try adjusting stationary threshold tolerance
- Verify sensor mounting is secure

### LED flickers in Smart Mode
- Normal during rapid ambient light changes
- May indicate marginal light threshold (~30 lux)
- Consider adjusting AMBIENT_DARK_THRESHOLD

## Firmware Information

**Build System:** nRF Connect SDK v3.1.1  
**Target Device:** Nordic nRF52833 (BL653 module)  
**RTOS:** Zephyr OS  
**Programming Interface:** SWD (Serial Wire Debug)

**Thread Architecture:**
- Main Thread: Button handling, system coordination
- Sensor Thread: 500ms sampling, environmental state updates
- Stationary Monitor: 60s periodic checks, auto-off logic
- Button ISR: Debounced input with callback

**Key Configuration Options:**
- `BRAKING_ACCEL_THRESHOLD`: -2.0 m/s² (in `sensor_data_collector.c`)
- `AMBIENT_DARK_THRESHOLD`: 30.0 lux (in `sensor_data_collector.c`)
- `SENSOR_BUFFER_SIZE`: 360 samples (in `sensor_data_collector.h`)
- `TIME_SAMPLING_INTERVAL_MS`: 500ms (in `sensor_data_collector.c`)

## Safety Notes

- This light is designed as a supplementary safety device
- Always use in conjunction with other bicycle lighting
- Ensure light is securely mounted to prevent detachment
- Regularly inspect mounting hardware for wear
- Replace battery according to manufacturer specifications
- Do not attempt to charge damaged or swollen batteries

## Compliance

**Electrical Safety:** Designed for low-voltage DC operation (3.0-4.2V)  
**EMC:** Bluetooth 5.1 compliant (2.4GHz ISM band)  
**Environmental:** Not waterproof - use in dry conditions or with protective cover

## License

Copyright © 2025 Matthias Dippold

This firmware is released under **GPLv3 + NonCommercial**.  
See LICENSE file for complete terms.

---

**Firmware Version:** 1.0.0 (Smart Mode Release)  
**Last Updated:** December 2025  
**For support and updates:** See main README.md

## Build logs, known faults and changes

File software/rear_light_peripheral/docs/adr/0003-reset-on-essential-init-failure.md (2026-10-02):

# Essential initialization failure resets the device

If the main LED, status LED or button fails to initialize, `main()` performs a software reset instead of returning. Returning leaves a dead device with no light and no way to wake it, while a reset gives a transient fault another chance and the boot policy then turns the light on (fail operational). The status LED is deliberately included to keep the rule simple, although it is not essential. A permanent hardware fault now causes a reset loop with no usable light, which is accepted. Battery, sensor and BLE failures do not reset.

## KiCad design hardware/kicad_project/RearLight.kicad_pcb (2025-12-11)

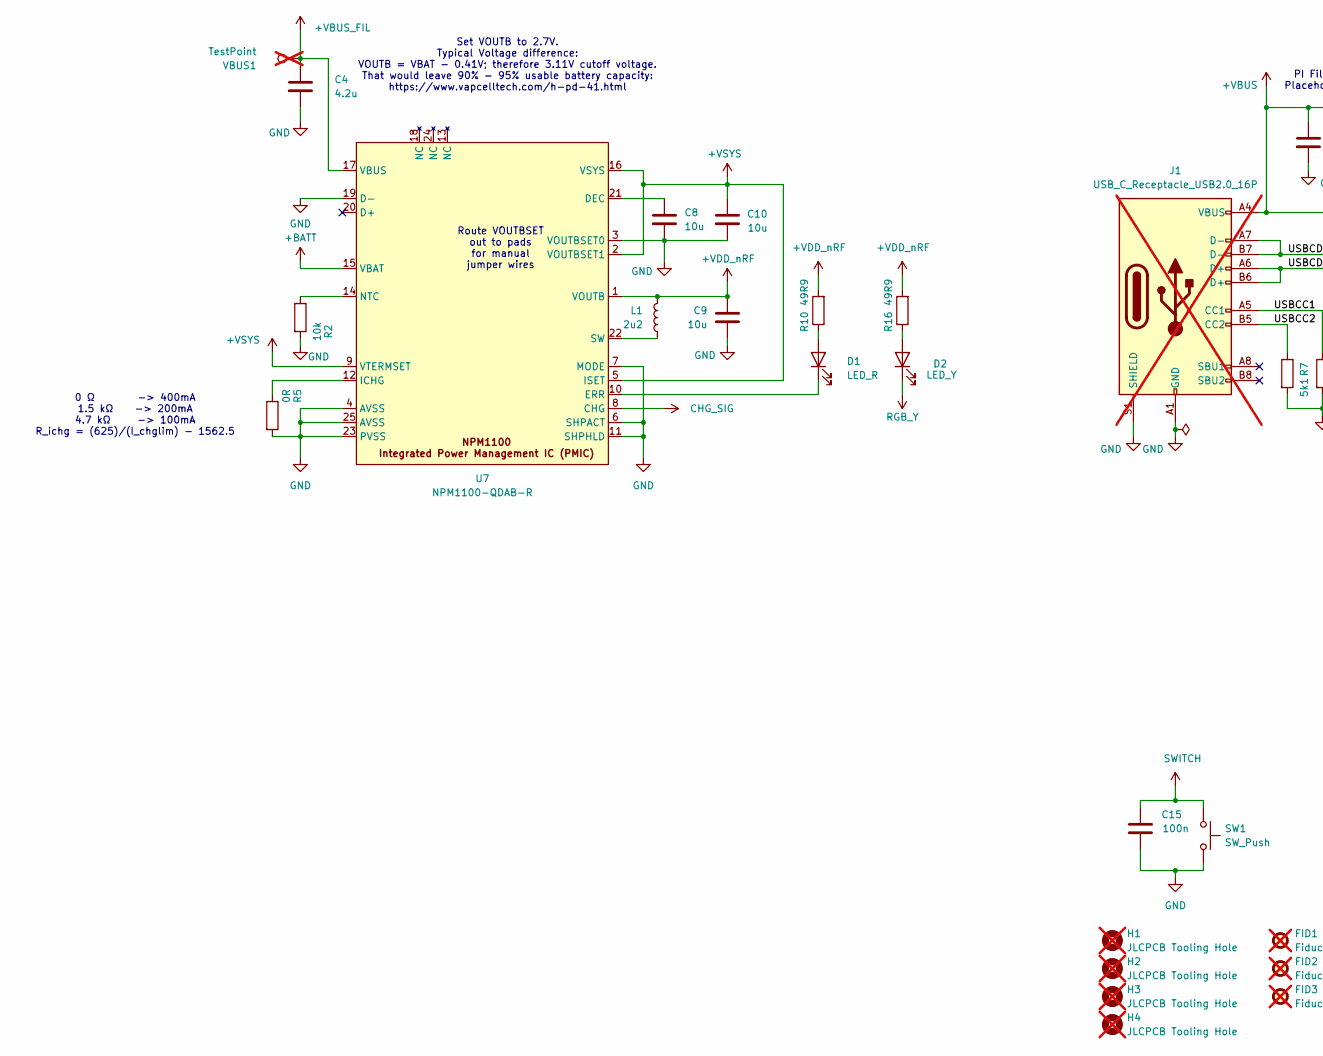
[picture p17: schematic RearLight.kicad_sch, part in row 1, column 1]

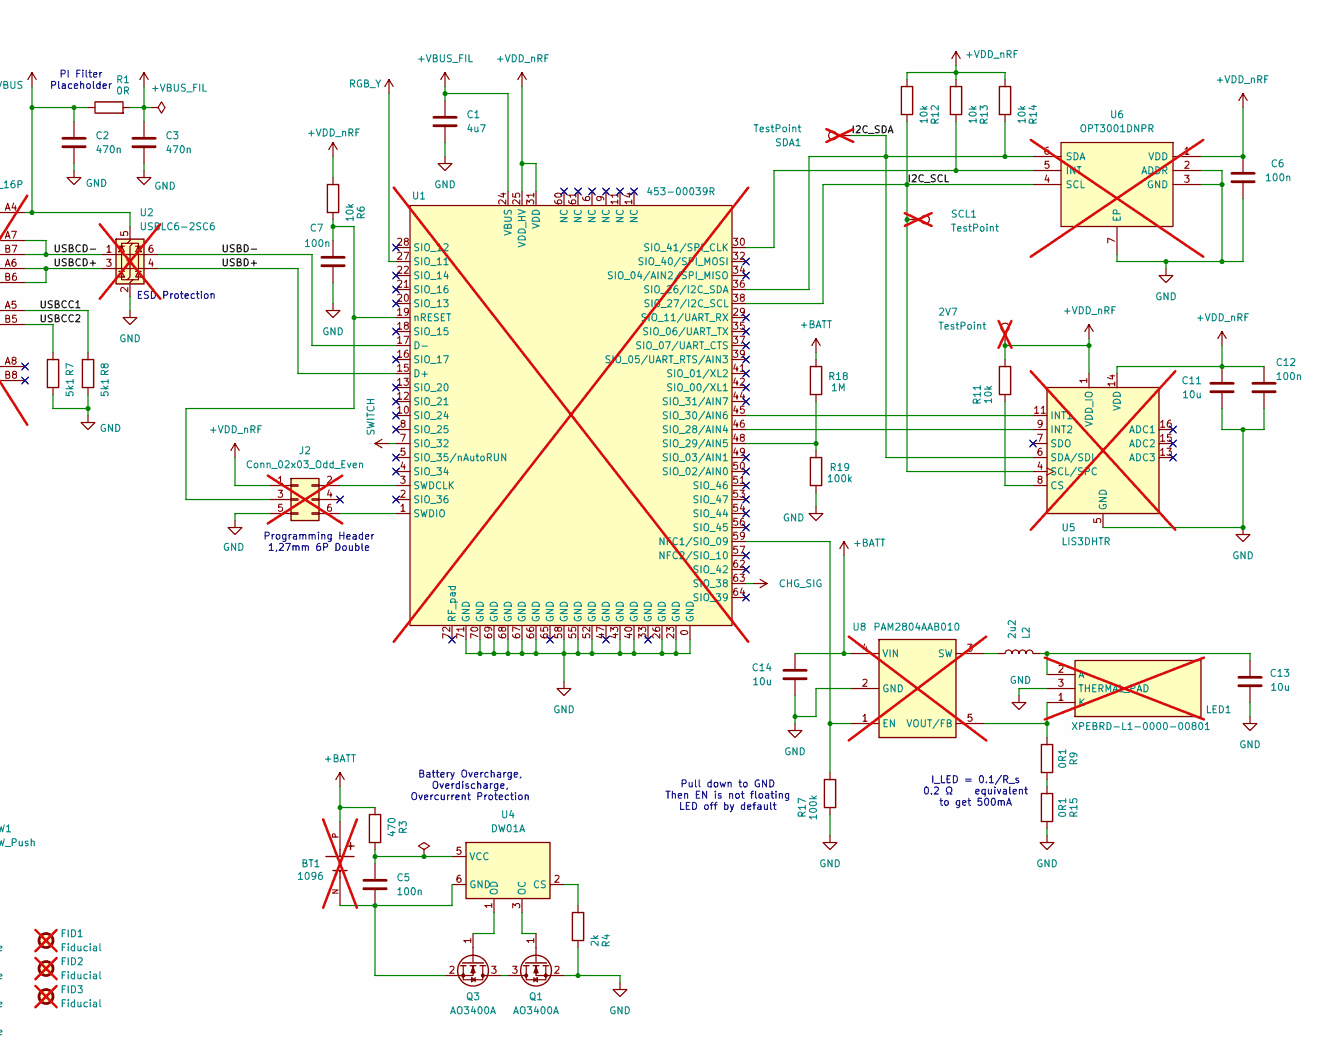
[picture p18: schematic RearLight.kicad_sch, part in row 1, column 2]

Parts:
2V7: TestPoint; TestPoint_Pad_D1.0mm; not fitted
BT1: 1096; BAT_1096_holes_slim; PARTREV A; DigiKey_Part_Number 36-1096-ND; not fitted
C1: 4u7; C_0805_2012Metric; LCSC C1779
C2, C3: 470n; C_0603_1608Metric_NO_SILK; LCSC C1623
C4: 4.2u; C_0805_2012Metric; LCSC C377773
C5, C6, C7, C12, C15: 100n; C_0805_2012Metric; LCSC C28233
C8, C9, C10, C11, C13, C14: 10u; C_0805_2012Metric; LCSC C15850
D1: LED_R; LED_0603_1608Metric; LCSC C2286
D2: LED_Y; LED_0805_2012Metric; LCSC C2296
FID1, FID2, FID3: Fiducial; Fiducial_1mm_Mask2mm; not fitted
H1, H2, H3, H4: JLCPCB Tooling Hole; ToolingHole_1.152mm; not fitted
J1: USB_C_Receptacle_USB2.0_16P; USB_C_Receptacle_GCT_USB4105-xx-A_16P_TopMnt_Horizontal_wid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; Manufacturer Part Number USB4105-GF-A-060; LCSC C3025063; not fitted
J2: Conn_02x03_Odd_Even; PinHeader_2x03_P1.27mm_Vertical; not fitted
L1, L2: 2u2; L_0805_2012Metric; LCSC C1043
LED1: XPEBRD-L1-0000-00801; XPEWHTL1000000E01; Manufacturer_Part_Number XPEBRD-L1-0000-00801; LCSC C5364087; not fitted
Q1, Q3: AO3400A; SOT-23; LCSC C20917
R1, R5: 0R; R_0603_1608Metric_NO_SILK; LCSC C21189
R2, R6, R12, R13, R14: 10k; R_0402_1005Metric_NO_SILK; Manufacturer Part Number 0402WGF1002TCE; LCSC C25744
R3: 470; R_0402_1005Metric_NO_SILK; Manufacturer Part Number 0402WGF4700TCE; LCSC C25117
R4: 2k; R_0402_1005Metric_NO_SILK; Manufacturer Part Number 0402WGF2001TCE; LCSC C4109
R7, R8: 5k1; R_0402_1005Metric_NO_SILK; Manufacturer Part Number 0402WGF5101TCE; LCSC C25905
R9, R15: 0R1; R_1206_3216Metric; Manufacturer Part Number 1206W4F100LT5E; LCSC C25334
R10, R16: 49R9; R_0402_1005Metric_NO_SILK; Manufacturer Part Number 0402WGF499JTCE; LCSC C25120
R11: 10k; R_0603_1608Metric_NO_SILK; Manufacturer Part Number 0603WAF1002T5E; LCSC C25804
R17, R19: 100k; R_0402_1005Metric_NO_SILK; Manufacturer Part Number 0402WGF1003TCE; LCSC C25741
R18: 1M; R_0402_1005Metric_NO_SILK; Manufacturer Part Number 0402WGF1004TCE; LCSC C26083
SCL1: TestPoint; TestPoint_Pad_D1.0mm; not fitted
SDA1: TestPoint; TestPoint_Pad_D1.0mm; not fitted
SW1: SW_Push; SW_TS-1088-AR02016; LCSC C720477
U1: 453-00039R; Laird_BL653; LCSC C6421506; not fitted
U2: USBLC6-2SC6; SOT-23-6; Manufacturer Part Number USBLC6-2SC6; LCSC C7519; not fitted
U4: DW01A; SOT-23-6; LCSC C18164398
U5: LIS3DHTR; LGA-16_3x3mm_P0.5mm_LayoutBorder3x5y; Manufacturer Part Number LIS3DHTR; LCSC C15134; not fitted
U6: OPT3001DNPR; SON65P200X200X65-7N-D; Mouser Part Number 595-OPT3001DNPR; not fitted
U7: NPM1100-QDAB-R; QFN50P400X400X90-25N-D; LCSC C5833729
U8: PAM2804AAB010; SOT95P280X100-5N; LCSC C71463; not fitted
VBUS1: TestPoint; TestPoint_Pad_D1.0mm; not fitted

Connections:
+BATT: BT1.P, C14.1, R3.1, R18.1, U7.15 (VBAT), U8.4 (VIN)
+VBUS: C2.1, J1.A4 (VBUS), J1.A9 (VBUS), J1.B4 (VBUS), J1.B9 (VBUS), R1.1, U2.5 (VBUS)
+VBUS_FIL: C1.1, C3.1, C4.1, R1.2, U1.24 (VBUS), U7.17 (VBUS), VBUS1.1
+VDD_nRF: 2V7.1, C6.1, C9.1, C11.1, C12.1, J2.1, L1.1, R6.1, R10.2, R11.1, R12.1, R13.1, R14.1, R16.2, U1.25 (VDD_HV), U1.31 (VDD), U5.1 (VDD_IO), U5.14 (VDD), U6.1 (VDD), U7.1 (VOUTB)
+VSYS: C10.1, U7.2 (VOUTBSET1), U7.5 (ISET), U7.9 (VTERMSET), U7.16 (VSYS)
/I2C_SCL: R12.2, SCL1.1, U1.38 (SIO_27/I2C_SCL), U5.4 (SCL/SPC), U6.4 (SCL)
/I2C_SDA: R14.2, SDA1.1, U1.36 (SIO_26/I2C_SDA), U5.6 (SDA/SDI), U6.6 (SDA)
/USBCC1: J1.A5 (CC1), R8.1
/USBCC2: J1.B5 (CC2), R7.1
/USBCD+: J1.A6 (D+), J1.B6 (D+), U2.3 (I/O2)
/USBCD-: J1.A7 (D-), J1.B7 (D-), U2.1 (I/O1)
/USBD+: U1.15 (D+), U2.4 (I/O2)
/USBD-: U1.17 (D-), U2.6 (I/O1)
CHG_SIG: U1.63 (SIO_38), U7.8 (CHG)
GND: C1.2, C2.2, C3.2, C4.2, C6.2, C7.2, C8.2, C9.2, C10.2, C11.2, C12.2, C13.2, C14.2, C15.2, J1.A1 (GND), J1.A12 (GND), J1.B1 (GND), J1.B12 (GND), J1.S1 (SHIELD), J2.5, LED1.3 (THERMAL_PAD), Q1.2 (S), R2.2, R4.2, R5.2, R7.2, R8.2, R15.2, R17.2, R19.2, SW1.2, U1.0 (GND), U1.23 (GND), U1.26 (GND), U1.40 (GND), U1.43 (GND), U1.52 (GND), U1.55 (GND), U1.58 (GND), U1.66 (GND), U1.67 (GND), U1.68 (GND), U1.69 (GND), U1.70 (GND), U1.71 (GND), U2.2 (GND), U5.5 (GND), U5.10 (GND), U5.12 (GND), U6.2 (ADDR), U6.3 (GND), U6.7 (EP), U7.3 (VOUTBSET0), U7.4 (AVSS), U7.6 (SHPACT), U7.7 (MODE), U7.11 (SHPHLD), U7.19 (D-), U7.23 (PVSS), U7.25 (AVSS), U8.2 (GND)
unnamed: D1.2 (A), R10.1
unnamed: D1.1 (K), U7.10 (ERR)
unnamed: D2.2 (A), R16.1
unnamed: J2.2, U1.3 (SWDCLK)
unnamed: C7.1, J2.3, R6.2, U1.19 (nRESET)
unnamed: J2.6, U1.1 (SWDIO)
unnamed: C13.1, L2.1, LED1.2 (A)
unnamed: LED1.1 (K), R9.1, U8.5 (VOUT/FB)
unnamed: Q1.3 (D), Q3.3 (D)
unnamed: Q1.1 (G), U4.3 (OC)
unnamed: Q3.1 (G), U4.1 (OD)
unnamed: BT1.N, C5.2, Q3.2 (S), U4.6 (GND)
unnamed: R9.2, R15.1
unnamed: R17.1, U1.59 (NFC1/SIO_09), U8.1 (EN)
unnamed: U1.46 (SIO_28/AIN4), U5.9 (INT2)
unnamed: R18.2, R19.1, U1.48 (SIO_29/AIN5)
unnamed: U1.45 (SIO_30/AIN6), U5.11 (INT1)
unnamed: R13.2, U1.30 (SIO_41/SPI_CLK), U6.5 (INT)
unnamed: R4.1, U4.2 (CS)
unnamed: C5.1, R3.2, U4.5 (VCC)
unnamed: R11.2, U5.8 (CS)
unnamed: C8.1, U7.21 (DEC)
unnamed: R5.1, U7.12 (ICHG)
unnamed: R2.1, U7.14 (NTC)
unnamed: L1.2, U7.22 (SW)
unnamed: L2.2, U8.3 (SW)
RGB_Y: D2.1 (K), U1.27 (SIO_11)
SWITCH: C15.1, SW1.1, U1.7 (SIO_32)

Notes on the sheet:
0 Ω -> 400mA 1.5 kΩ -> 200mA 4.7 kΩ -> 100mA R_ichg = (625)/(I_chglim) - 1562.5
Programming Header 1,27mm 6P Double
Set VOUTB to 2.7V. Typical Voltage difference: VOUTB = VBAT - 0.41V; therefore 3.11V cutoff voltage. That would leave 90% - 95% usable battery capacity: https://www.vapcelltech.com/h-pd-41.html
Route VOUTBSET out to pads for manual jumper wires
ESD Protection
I_LED = 0.1/R_s 0.2 Ω equivalent to get 500mA
PI Filter Placeholder
Pull down to GND Then EN is not floating LED off by default
Battery Overcharge, Overdischarge, Overcurrent Protection

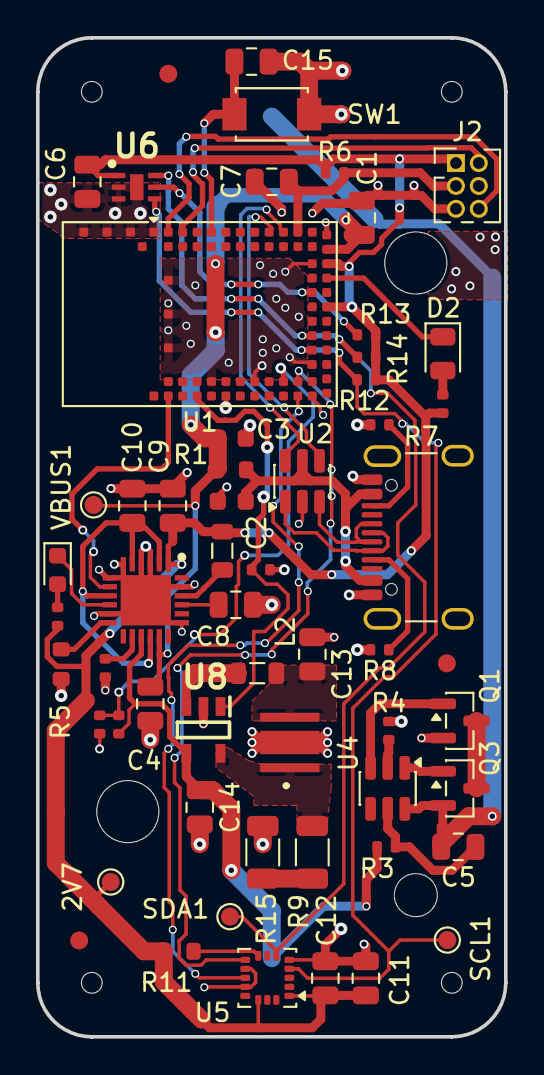
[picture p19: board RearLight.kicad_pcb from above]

Board: 2 copper layers, 26.0 x 55.5 mm, 63 parts (1 on the bottom side), 43 nets.

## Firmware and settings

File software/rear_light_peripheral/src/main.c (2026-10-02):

/*
 * Copyright (c) 2025 Matthias Dippold
 *
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
 * NON-COMMERCIAL USE CLAUSE:
 * Permission is granted to use, copy, modify, and distribute this software
 * and its derivatives for NON-COMMERCIAL purposes only. Commercial use of
 * this software, in whole or in part, is strictly prohibited without
 * explicit written permission from the copyright holder.
 */

#include <zephyr/kernel.h>
#include <zephyr/device.h>
#include <zephyr/devicetree.h>
#include <zephyr/drivers/hwinfo.h>
#include <zephyr/sys/reboot.h>

#include "app_events.h"
#include "state_machine.h"
#include "light.h"
#include "status_led.h"
#include "button.h"
#include "sensors.h"
#include "battery.h"
#include "ble.h"
#include "power.h"
#include "debug.h"
#ifdef DEBUG
#include "i2c_scanner.h"
#endif

/* Time to let the last debug message drain before a software reset */
#define RESET_FLUSH_DELAY_MS 100

/**
 * @brief Recover from a failed essential initialization by resetting
 *
 * Returning from main() would leave the device dead (no light, no button).
 * A software reset gives a transient fault another chance, and the boot
 * policy brings the light back on afterwards (fail operational).
 */
static FUNC_NORETURN void fatal_reset(const char *what, int err)
{
    debug_printk("%s failed: %d - resetting\n", what, err);

    /* Give the debug output time to drain before the reset */
    k_msleep(RESET_FLUSH_DELAY_MS);

    sys_reboot(SYS_REBOOT_COLD);
}

int main(void)
{
    int err;
    uint32_t boot_reset_cause = 0;
    bool boot_usb_connected;

    debug_printk("System starting...\n");

    /* Capture reset reason and USB state immediately at boot */
    power_log_reset_cause(&boot_reset_cause);
    boot_usb_connected = power_usb_present();
    debug_printk("USB VBUS: %s\n", boot_usb_connected ? "connected" : "not connected");

    /* Output hardware must be up before the state machine enters its
     * boot state */
    err = light_init();
    if (err != 0) {
        fatal_reset("Main LED init", err);
    }

    err = status_led_init();
    if (err != 0) {
        fatal_reset("Status LED init", err);
    }

    /* Non-fatal: battery sampling retries its ADC setup, and the light
     * works without sensors (SMART mode just stays dark) or BLE */
    err = battery_init();
    if (err != 0) {
        debug_printk("Battery ADC init failed: %d\n", err);
    }

    err = sensors_init();
    if (err != 0) {
        debug_printk("Sensor init failed: %d\n", err);
    }

    err = ble_init();
    if (err != 0) {
        debug_printk("BLE init failed: %d\n", err);
    }

    err = button_init();
    if (err != 0) {
        fatal_reset("Button init", err);
    }

#ifdef DEBUG
    /* Scan I2C bus for debugging */
    const struct device *const i2c_dev = DEVICE_DT_GET(DT_NODELABEL(i2c0));

    if (device_is_ready(i2c_dev)) {
        debug_printk("Scanning I2C bus during initialization...\n");
        scan_i2c_bus(i2c_dev);
    } else {
        debug_printk("I2C bus not available for scanning\n");
    }
#endif

    /* Boot into IDLE_CHARGING only on a power-on reset with USB present;
     * any other boot (including a wake from System OFF) turns the light on
     * in the first Active Mode */
    enum system_state boot_state = sm_first_active_mode();

    if ((boot_reset_cause & RESET_POR) && boot_usb_connected) {
        debug_printk("USB POR with VBUS connected - booting into IDLE_CHARGING\n");
        boot_state = IDLE_CHARGING;
    }

    sm_init(boot_state, boot_usb_connected);

    power_usb_poll_start();

    /* Enable button interrupts AFTER slow initialization tasks so no
     * spurious events are queued during boot/wake-up */
    err = button_enable();
    if (err != 0) {
        fatal_reset("Button interrupt enable", err);
    }

    debug_printk("Initialization complete. Ready for events...\n");

    /* Main thread becomes the state machine thread */
    sm_run();

    return 0;
}

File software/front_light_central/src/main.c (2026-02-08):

/*
 * Copyright (c) 2025 Matthias Dippold
 *
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
 * NON-COMMERCIAL USE CLAUSE:
 * Permission is granted to use, copy, modify, and distribute this software
 * and its derivatives for NON-COMMERCIAL purposes only. Commercial use of
 * this software, in whole or in part, is strictly prohibited without
 * explicit written permission from the copyright holder.
 */

#include <zephyr/kernel.h>
#include <zephyr/drivers/gpio.h>
#include <zephyr/devicetree.h>
#include <zephyr/pm/device.h>
#include <zephyr/sys/poweroff.h>

#include "utils.h"
#include "button.h"
#include "main_state_machine.h"
#include "sensor_data_collector.h"
#include "power_management.h"
#include "ble_central.h"
#ifdef DEBUG
#include "i2c_scanner.h"
#endif

/* Global sensor buffer and environmental state */
sensor_buffer_t g_sensor_buffer;
environmental_state_t g_env_state;

static void button_event_handler(enum button_press_type press_type)
{
    ARG_UNUSED(press_type);
    
    /* Advance state machine on button press.
     * Note: the actual state transition happens asynchronously via k_work
     * in main_state_machine_on_button_press, so we cannot immediately check
     * the new state here. Sleep/poweroff is not used on the front light central. */
    main_state_machine_on_button_press();
}

int main(void)
{
    int ret;
    
    debug_printk("System starting...\n");
    
    /* Initialize global sensor buffer */
    pthread_rwlock_init(&g_sensor_buffer.lock, NULL);
    g_sensor_buffer.write_index = 0;
    
    /* Initialize environmental state to safe defaults */
    g_env_state.is_braking = false;
    g_env_state.ambient_dark = false;
    g_env_state.previous_brightness = 0;
    
    /* Initialize main state machine (LED control) */
    ret = main_state_machine_init();
    if (ret != 0) {
        /* State machine initialization failed */
        return -1;
    }
    
    /* Initialize Bluetooth Low Energy */
    ret = bluetooth_init();
    if (ret != 0) {
        debug_printk("BLE Init failed: %d\n", ret);
        /* Continue anyway - BLE is optional */
    } else {
        debug_printk("BLE initialized successfully\n");
    }
    debug_printk("Statement after BLE initialization\n");
    
    /* Initialize button GPIO (but don't enable interrupts yet) */
    int err = -1;
    err = button_init(button_event_handler);
	if (err) {
		debug_printk("Button Init failed: %d\n", err);
		return err;
	}
	debug_printk("Button GPIO configured (interrupts not yet enabled)...\n");
    
#ifdef DEBUG
    /* Scan I2C bus for debugging */
    const struct device *const i2c_dev = DEVICE_DT_GET(DT_NODELABEL(i2c0));
    if (i2c_dev != NULL && device_is_ready(i2c_dev)) {
        debug_printk("Scanning I2C bus during initialization...\n");
        scan_i2c_bus(i2c_dev);
    } else {
        debug_printk("I2C bus not available for scanning\n");
    }
#endif
    
    /* Enable button interrupts AFTER slow initialization tasks
     * This prevents spurious button events during I2C scanning and other init */
    err = button_enable_interrupts();
    if (err) {
        debug_printk("Button interrupt enable failed: %d\n", err);
        return err;
    }
    debug_printk("Button interrupts enabled. Ready for events...\n");
    
    /* Main loop (only reached if NOT in LED_OFF state) */
    while (1) {
        /* Sleep to save power - timers and interrupts will wake the CPU */
        k_msleep(1000);
    }

    return 0;
}

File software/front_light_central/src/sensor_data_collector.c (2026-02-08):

/*
 * Copyright (c) 2025 Matthias Dippold
 *
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
 * NON-COMMERCIAL USE CLAUSE:
 * Permission is granted to use, copy, modify, and distribute this software
 * and its derivatives for NON-COMMERCIAL purposes only. Commercial use of
 * this software, in whole or in part, is strictly prohibited without
 * explicit written permission from the copyright holder.
 */

#include <zephyr/kernel.h>
#include <zephyr/device.h>
#include <zephyr/devicetree.h>
#include <zephyr/drivers/sensor.h>
#include <zephyr/sys/atomic.h>

#include "sensor_data_collector.h"
#include "utils.h"
#include "light_modes.h"
#include "main_state_machine.h"
#include "power_management.h"

#define SENSOR_THREAD_PRIORITY 7
#define SENSOR_THREAD_STACK_SIZE 2048
#define TIME_SAMPLING_INTERVAL_MS 500  /* Changed to 500ms for 360 samples = 3 minutes */

/* Braking detection thresholds */
#define BRAKING_ACCEL_THRESHOLD -3.0  /* m/s^2, negative z-axis for rear light */
#define AMBIENT_DARK_THRESHOLD 50.0   /* lux - threshold to enter dark mode */
#define AMBIENT_BRIGHT_THRESHOLD 150.0 /* lux - threshold to exit dark mode (hysteresis) */
#define AMBIENT_DARK_SAMPLES_REQUIRED 2  /* Number of consecutive samples required to change state */

/* Static variables for braking detection (need 2 consecutive samples) */
static bool prev_sample_braking = false;

/* Static variables for ambient light debouncing */
static uint8_t ambient_dark_sample_count = 0;
static uint8_t ambient_bright_sample_count = 0;

/* Sensor sampling control (shared between main thread and sensor thread) */
static atomic_t sensor_sampling_active = ATOMIC_INIT(0);
static struct k_thread *sensor_thread_handle = NULL;
K_SEM_DEFINE(sensor_sampling_sem, 0, 1);

/* Forward declarations */
static void write_sensor_data(const sensor_readings_t *value);
static void update_environmental_state(const sensor_readings_t *value);

static const struct device *get_temp_sensor(void){

    const struct device *const dev = DEVICE_DT_GET(DT_NODELABEL(temp));

    if (dev == NULL) {
        /* No such node, or the node does not have status "okay"*/
        debug_printk("Error: Temperature sensor not found\n");
        return NULL;
    }

    if (!device_is_ready(dev)) {
        debug_printk("Error: Device %s not ready\n"
            "Check the driver initialization logs for errors.", dev->name);
        return NULL;
    }

    return dev;
}

static const struct device *get_light_sensor(void){

    const struct device *const dev = DEVICE_DT_GET(DT_NODELABEL(opt3001));

    if (dev == NULL) {
        /* No such node, or the node does not have status "okay"*/
        debug_printk("Error: OPT3001 device tree node not found\n");
        return NULL;
    }
    
    if (!device_is_ready(dev)) {
        debug_printk("Error: Device %s not ready\n"
            "Check the driver initialization logs for errors.\n", dev->name);
        return NULL;
    }

    return dev;
}

static const struct device *get_accel_sensor(void){

    const struct device *const dev = DEVICE_DT_GET(DT_NODELABEL(lis3dh));
    
    if (dev == NULL) {
        /* No such node, or the node does not have status "okay"*/
        debug_printk("Error: LIS3DH device tree node not found\n");
        return NULL;
    }
    
    if (!device_is_ready(dev)) {
        debug_printk("Error: Device %s not ready\n"
            "Check the driver initialization logs for errors.\n", dev->name);
        return NULL;
    }

    return dev;
}

/**
 * @brief Write sensor data to circular buffer
 * 
 * Thread-safe write using pthread rwlock.
 * 
 * @param value Sensor readings to write
 */
static void write_sensor_data(const sensor_readings_t *value)
{
    pthread_rwlock_wrlock(&g_sensor_buffer.lock);
    
    uint16_t idx = g_sensor_buffer.write_index;
    
    g_sensor_buffer.temp[idx] = value->temp;
    g_sensor_buffer.light[idx] = value->light;
    g_sensor_buffer.accel_x[idx] = value->accel_x;
    g_sensor_buffer.accel_y[idx] = value->accel_y;
    g_sensor_buffer.accel_z[idx] = value->accel_z;
    
    /* Increment write index (circular buffer) */
    g_sensor_buffer.write_index = (idx + 1) % SENSOR_BUFFER_SIZE;
    
    pthread_rwlock_unlock(&g_sensor_buffer.lock);
}
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

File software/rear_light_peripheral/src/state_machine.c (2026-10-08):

/*
 * Copyright (c) 2025 Matthias Dippold
 *
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
 * NON-COMMERCIAL USE CLAUSE:
 * Permission is granted to use, copy, modify, and distribute this software
 * and its derivatives for NON-COMMERCIAL purposes only. Commercial use of
 * this software, in whole or in part, is strictly prohibited without
 * explicit written permission from the copyright holder.
 */

#include <zephyr/kernel.h>
#include <zephyr/sys/atomic.h>
#include <zephyr/sys/printk.h>

#include "state_machine.h"
#include "app_events.h"
#include "light.h"
#include "status_led.h"
#include "button.h"
#include "sensors.h"
#include "battery.h"
#include "power.h"
#include "debug.h"

/* External state writes (BLE) are ignored while the local state changed
 * less than this long ago, so a remote cannot fight a just-pressed button. */
#define BLE_STABLE_WINDOW_MS 3000

/* Selection window: after the light goes from an inactive state (Deep Sleep,
 * Off, Idle Charging) to an Active Mode, short presses cycle through the
 * Active Modes only for this many battery ticks. Afterwards a short press
 * leaves the Active Modes for the end state of the cycle (Idle Charging or
 * Deep Sleep).
 *
 * The window is counted in battery ticks (the existing free-running 5 s
 * sampling tick) instead of a dedicated timer. The tick phase is random
 * relative to the switch-on, so 4 ticks last between 15 and 20 s. */
#define MODE_SELECT_WINDOW_BATTERY_TICKS 4

/* FLASH mode: double flash every 1.5 s
 * (peak 70 ms, base 70 ms, peak 70 ms, base for the rest of the cycle) */
#define FLASH_CYCLE_MS 1500
#define FLASH_STEP_MS  70
#define FLASH_REST_MS  (FLASH_CYCLE_MS - 3 * FLASH_STEP_MS)

/* Maximum time to wait for button release before entering System OFF.
 * Entering System OFF with the wake level already active would wake
 * (reset) the system immediately. */
#define POWEROFF_RELEASE_WAIT_MS   10000
#define POWEROFF_RELEASE_POLL_MS   20

/* Mode Cycle: the Active Modes in short-press order. This is the only place
 * that knows the order - the end of the cycle (Idle Charging or Deep Sleep)
 * and the entry point (first mode) are derived from it. */
static const enum system_state mode_cycle[] = {
    LED_SMART_MODE,
    LED_50_PERCENT,
    LED_50_80_FLASH,
};

#define MODE_CYCLE_LEN ARRAY_SIZE(mode_cycle)

/* All of the following is owned exclusively by the state machine thread. */
static enum system_state state;
static atomic_t published_state = ATOMIC_INIT(LED_OFF);
static int64_t last_change_ms;

/* Battery ticks since the light was last switched on from an inactive state;
 * saturates at MODE_SELECT_WINDOW_BATTERY_TICKS (window closed) */
static uint8_t selection_ticks = MODE_SELECT_WINDOW_BATTERY_TICKS;

static bool usb_present;
static bool low_battery;
static bool braking;
static bool ambient_dark;
static uint8_t flash_phase;

static struct k_timer flash_timer;

/* Timer ISR only posts an event; the PWM write happens in the SM thread */
static void flash_timer_expiry(struct k_timer *timer)
{
    ARG_UNUSED(timer);
    app_event_post(EVT_FLASH_STEP, 0);
}

/* Position of a state in the Mode Cycle, or -1 if it is not an Active Mode */
static int cycle_index(enum system_state s)
{
    for (size_t i = 0; i < MODE_CYCLE_LEN; i++) {
        if (mode_cycle[i] == s) {
            return (int)i;
        }
    }

    return -1;
}

static bool light_is_on(enum system_state s)
{
    return cycle_index(s) >= 0;
}

static void status_refresh(void)
{
    status_led_set(low_battery, usb_present, light_is_on(state));
}

/* SMART mode brightness priority: braking > ambient dark > off */
static void apply_smart_pwm(void)
{
    if (braking) {
        light_set(LIGHT_PULSE_PEAK);
    } else if (ambient_dark) {
        light_set(LIGHT_PULSE_BASE);
    } else {
        light_set(LIGHT_PULSE_OFF);
    }
}

static void state_enter(enum system_state s)
{
    switch (s) {
    case LED_OFF:
        light_set(LIGHT_PULSE_OFF);
        break;
    case LED_50_PERCENT:
        light_set(LIGHT_PULSE_BASE);
        break;
    case LED_50_80_FLASH:
        light_set(LIGHT_PULSE_BASE);
        flash_phase = 0;
        k_timer_start(&flash_timer, K_MSEC(FLASH_CYCLE_MS), K_NO_WAIT);
        break;
    case LED_SMART_MODE:
        braking = false;
        ambient_dark = false;
        light_set(LIGHT_PULSE_OFF);
        sensors_start();
        break;
    case IDLE_CHARGING:
        light_set(LIGHT_PULSE_OFF);
        break;
    }
}

static void state_exit(enum system_state s)
{
    switch (s) {
    case LED_50_80_FLASH:
        k_timer_stop(&flash_timer);
        break;
    case LED_SMART_MODE:
        sensors_stop();
        break;
    default:
        break;
    }
}

static void transition(enum system_state to)
{
    if (to == state) {
        return;
    }

    debug_printk("State transition: %d -> %d\n", state, to);

    bool was_active = light_is_on(state);

    state_exit(state);
    state = to;
    state_enter(to);

    last_change_ms = k_uptime_get();

    /* Only an inactive -> Active Mode transition opens the selection window;
     * changes between Active Modes neither open nor restart it */
    if (!was_active && light_is_on(to)) {
        selection_ticks = 0;
    }

    atomic_set(&published_state, to);
    status_refresh();
}

/**
 * @brief Shut everything down and enter System OFF (deep sleep)
 *
 * Called only from the state machine thread, synchronously - there is no
 * delayed sleep work that a button press could race against. If the button
 * wake configuration fails, the device stays awake in LED_OFF with a
 * working button instead of ending up with dead inputs.
 */
static void do_poweroff(void)
{
    debug_printk("Powering off...\n");

    state_exit(state); /* stops flash timer / sensor sampling */
    light_set(LIGHT_PULSE_OFF);
    status_led_off();

    /* Wait for button release: the long press that triggered this fires
     * while the button is still held, and System OFF would wake (reset)
     * immediately with the wake level already active. A genuinely stuck
     * button proceeds after the timeout and causes a visible wake+reboot
     * instead of a dead device. */
    for (int i = 0; i < POWEROFF_RELEASE_WAIT_MS / POWEROFF_RELEASE_POLL_MS &&
                    button_is_pressed(); i++) {
        k_msleep(POWEROFF_RELEASE_POLL_MS);
    }

    if (button_prepare_wake() != 0) {
        /* Recover instead of sleeping with a dead button: restore edge
         * interrupts and stay awake in LED_OFF so the user can retry. */
        debug_printk("Wake configuration failed - staying awake in LED_OFF\n");
        (void)button_reenable();
        state = LED_OFF;
        last_change_ms = k_uptime_get();
        atomic_set(&published_state, LED_OFF);
        status_refresh();
        return;
    }

    power_off_finalize(); /* does not return */
}
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

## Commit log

2025-11-07 Added kicad project (schematic)
    [RearLight.kicad_pcb, RearLight.kicad_sch, untitled.kicad_sch]
2025-11-08 Schematic first draft, review needed
    [RearLight.kicad_pcb, RearLight.kicad_sch, untitled.kicad_sch]
2025-11-15 Schematic done; Layout first draft
    [1096.step, BL653 453-00039_3D Model with label.STEP, LTRB_RASF.01-6B6C-C3E6-0-0-R18.stp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]
2025-11-18 Layout 2nd draft
    Todo: increase via size
    [RearLight.kicad_pcb, RearLight.kicad_sch, Vapcell_18350_2A_DischargeCurve.csv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]
2025-11-18 DFM design overhaul
    [LED_LTST-C170KSKT_LTO.step, LTST-C190KRKT.step, RearLight.kicad_pcb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]
2025-11-19 Added correct tooling holes for JLCPCB assembly
    [RearLight.kicad_pcb, RearLight.kicad_sch]
2025-11-19 better placement & silkscreen for DFM
    [RearLight.kicad_pcb, RearLight.kicad_sch]
2025-11-19 Added total cost calculation spredsheet
    [Cost.xlsx]
2025-11-19 Added 100k pulldown to LED driver EN
    [RearLight.kicad_pcb, RearLight.kicad_sch]
2025-11-20 Production Version 1.0
    Moved red LED to NPM1100
    [RearLight.kicad_pcb, RearLight.kicad_sch]
2025-11-21 Updated actual cost of oredered parts.
    [Cost.xlsx]
2025-12-11 updated board thickness to 1.6 mm
    The board was manufactured with 1.6 mm board thickness accidentaly.
    To reflect this, updated the kicad project as well.
    [RearLight.kicad_pcb, RearLight.kicad_sch]
2025-12-24 Simple LED on/off control w/ 50% PWM duty cycle
2025-12-25 Refactor & Add strict compiler warnings
    - Moved button_control functionallity to main.
    - Enable -Wall, -Wextra, and -Werror for stricter code quality
    - Link math library (-lm) for future sensor calculations
2025-12-25 Added temperature sensor
2025-12-27 Added accellerometer sensor
2025-12-27 Added DEBUG parameter to exclude printing
2025-12-27 Fixed too fast PWM frequency
    100us period got filtered out by the series inductor with the power LED
    1ms period is appropriate for dimming functions.
    [button.c, light_modes.c, main.c]
2026-01-04 Added Sleep mode & Smart mode
    Sleep mode uses ~20 uA (device off) w/ wake button interrupt.
    Smart Mode controls the led brightness based on braking deceleration & abient light.
2026-01-08 Code simplification according to comments attached
    MAIN.C
    Constant definitions
    - Get the status led integer definition from DT
    X - Set the PWM width for the Status Led to 500ms --> rename TIMER_INTERVAL_MS to STATUS_TIMER_INTERVAL
    - Get the device tree specifications (pointer to gpio_dt_spec) from the status led
    X - Define a k_timer led_timer for the status led --> rename to status_led_timer
    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
2026-01-16 Added short and long press detection
    [button.c, main.c]
2026-01-21 State machine to OFF after 10s of button inactivity
2026-01-30 Added correct BLE functionality
    A bug that prevents the peripheral to enter sleep mode after smart mode exists
    This bug is there after the first sleep cycle. Something is not configured correctly.
    [button.c, light_modes.c, main.c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]
2026-02-08 Several Fixes
    sensor_data_collector.c -- 5 fixes:
    Busy-loop fix: Added k_sleep(K_SECONDS(150)) before continue in stationary monitor
    Integer math: Replaced double + sqrt() with sensor_value_to_milli() + squared-magnitude comparison, removed <math.h>
    Atomic flag: sensor_sampling_active changed from bool to atomic_t
    Stack sizes: Both thread stacks increased from 1024 to 2048
    Zero-init: sensor_readings_t value now = {0} to avoid uninitialized reads
    light_modes.c -- 2 fixes:
    ISR-safe PWM: Timer expiry callbacks now submit k_work items instead of calling pwm_set_pulse_dt() directly from ISR
    Atomic flags: blinking_active and flash_step changed to atomic_t
    button.c -- 1 fix (additional to rear ligh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
    [button.c, light_modes.c, main.c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]
2026-02-15 Removed startup timer doing nothing
2026-02-15 Added adc readings of battery voltage
2026-02-15 Auto shut-off below 3V; low battery indication below 3.4V
2026-05-19 Added status LED low battery indicator (blinking)
2026-10-11 fix(sleep): use System ON idle for Deep Sleep
    System OFF sometimes left the light unwakeable by
    button or USB; only reset or battery removal recovered
    it. Idle with peripherals stopped keeps the normal
    GPIO wake path. See ADR-0004.
2026-10-11 fix(smart): measure ambient light with LED blanked, single threshold
    Replace the dark/bright threshold pair with AMBIENT_THRESHOLD_MILLILUX
    (30 lx) plus a fixed 10 lx off offset. The main LED's light reflected
    into the OPT3001 inside the housing, ended the darkness by itself and
    caused an on/off oscillation.
    While the LED is lit at Base, ambient light is now measured with the
    LED briefly blanked (about 125 ms, every 30 s). The OPT3001 needs at
    least 100 ms of integration, so a 1 ms blank is not possible.
    - add light_blank_begin()/light_blank_end(); light_set() during a blank
    only records the level, and the latest request is applied afterwards
    - set the OPT3001 to 100 ms conversion (driver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
2026-11-07 feat(rear_light_ant): add ANT+ rear light firmware rewrite
    Add a new event-driven firmware for the rear light that replaces the
    BLE-based design with ANT+ (see ADR-0005). The old code is not part of
    this change; the new tree lives under software/rear_light_ant/.
    Structure:
    - state machine in sm.c/sm.h, driven by events from app_events
    - bike_light, light, power, battery and battery_logic for behaviour
    - sensors and detectors for ambient light, motion and stationary
    detection (ADR-0002)
    - ant_link for ANT+ transport; ant control is unauthenticated (ADR-0001)
    - soft_timer, twim, status_led, button and startup for platform support
    - stats.h plus tools/ (inject, rate, stats, watch) for bench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
2026-11-07 feat(smart): park when stationary and wake on motion
    Smart no longer powers off after the stationary timeout. It parks: the
    main LED and light sensor are off, the LIS3DH runs only its low-power
    motion detector (10 Hz, high-pass filtered, 300 mg threshold, latched
    in INT1_SRC), and the status LED flashes 30 ms every 5 s. The INT pins
    are not wired, so the latch is polled once per second. Motion returns
    to full Smart by itself. Parked is a phase of Smart, not a state: the
    button rules, the Selection Window and the ANT+ report (Auto) are
    unchanged, the ANT channel stays open, and there is no park timeout.
    If the motion detector cannot be set up, Smart keeps normal sampling.
    The earlier behavio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
2026-11-07 feat(front): build the ANT+ front light as a variant of the rear firmware
    The front light uses the rear light's board with a white LED. The same
    source now builds both: `make` is the rear light, `make LIGHT=front`
    the front light (ADR-0009). Build output moves to build/rear/ and
    build/front/; every board command takes LIGHT=front for the front.
    Front light:
    - Mode Cycle Smart, Standard (30 %), Bright (80 %)
    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
2026-11-07 feat(front): control the rear light as an ANT+ Bike Lights controller
    The front light now switches the rear light without a bike computer.
    It opens a second ANT channel (slave) and sends the rear the same light
    settings command (page 34) a Wahoo sends, so it takes the controller
    role of the existing ANT+ Bike Lights profile. The rear needs no change
    for that (ADR-0010, SPEC section 12).
    - Finding the rear: at every wake the front searches by proximity
    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
2026-11-07 fix(front): find the rear by a measured dBm threshold
    The front often did not find the rear at mounting distance: the ANT
    proximity bins are specified for nRF51 and were too strict for these
    boards (bin 3 needed the boards almost touching, bin 5, about -60 dBm,
    missed the rear often).
    The front now logs the RSSI of every page from the rear (ANT extended
    messages) in the debug counters ("rear rssi" in make stats). Measured
    indoors, 30 s each, proximity off:
    1-1.5 m (mounting distance) -72..-51 dBm, median -62
    about 3 m -81..-56 dBm, median -67
    5-10 m -83..-60 dBm, median -69
    The first find now uses a custom threshold, REAR_PROXIMITY_DBM -75,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
2026-11-12 feat(haystack): send a Find My advert from a radio timeslot
    Raw ADV_NONCONN_IND on channels 37/38/39 inside an S212 Radio Timeslot,
    next to the ANT channel, no BLE stack (ADR-0011). Key source is either a
    fixed OpenHaystack key (HAYSTACK_KEY_<LIGHT>) or a host-precomputed table
    of a cloned AirTag's rotating keys (gen_airtag_table.py), advanced on
    uptime. track.py reads reports back through FindMy.py.
2026-11-12 feat(haystack): derive cloned AirTag keys on the light
    Replace the host-precomputed key table with the AirTag's own key
    schedule run on device (ADR-0012): SK chain via X9.63-KDF-SHA256 and
    P_i = u*P0 + v*G on P-224 (micro-ecc, tinycrypt), from the public master
    key only. The key index persists in a 3-page flash key store written
    through the SoftDevice and is provisioned by provision_airtag.py via
    `make flash-keys` (also run by `make flash`).
    No RTC: rotation runs on uptime at 15 min + 0.1 %, so the light can lag
    Apple's schedule (re-aligned by reports) but never lead it. Rotation is
    checked on its own soft timer, since SoftDevice events are rare in Deep
    Sleep. Host tests compare against Fin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
2026-11-12 docs(adr-0012): record bench results of on-device key rotation
    Measured on the rear with the ANT channel open: 177 ms per key
    derivation, no flash errors, page change and resume after reset
    verified against FindMy.py keys.
2026-11-12 feat(haystack): send the AirTag's daily backup key chain too
    A real AirTag away from its owner sends its backup (secondary) key
    chain, derived from SKS and stepped once a day. It is unknown which
    chain Apple looks up for the light, so adverts now alternate main and
    backup key, each with its own address.
    The backup index follows from the main one as i / 96 + 1, the lower of
    FindMy.py's two candidates, so the light still never leads. Only the
    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

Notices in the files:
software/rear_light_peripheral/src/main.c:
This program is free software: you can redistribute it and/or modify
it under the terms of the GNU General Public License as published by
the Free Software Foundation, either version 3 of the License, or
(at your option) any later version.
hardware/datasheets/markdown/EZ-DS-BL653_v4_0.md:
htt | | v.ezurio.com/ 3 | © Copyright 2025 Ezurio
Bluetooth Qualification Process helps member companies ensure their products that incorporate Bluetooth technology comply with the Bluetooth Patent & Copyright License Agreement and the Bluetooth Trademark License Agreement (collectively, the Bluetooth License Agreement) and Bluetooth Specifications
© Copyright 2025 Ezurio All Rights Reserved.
